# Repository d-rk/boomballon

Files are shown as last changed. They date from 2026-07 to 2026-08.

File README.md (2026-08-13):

<p align="center">
  Boom Balloon logo
</p>

# Boom Balloon

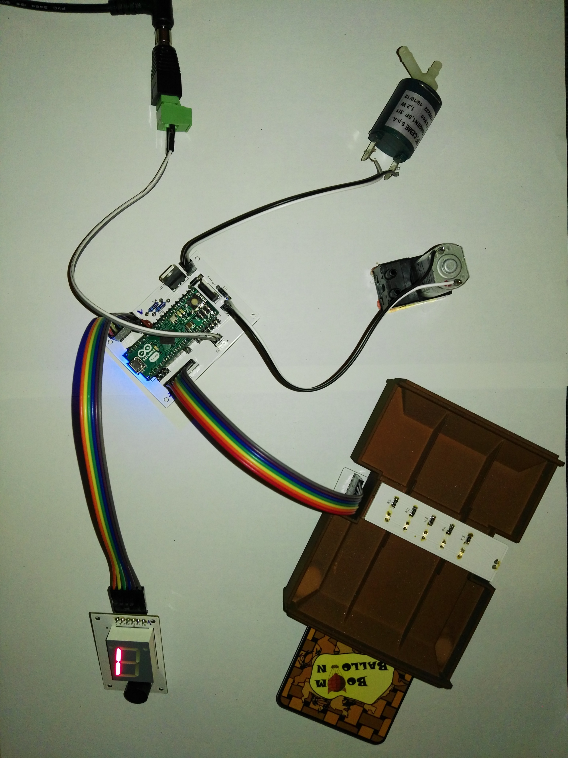
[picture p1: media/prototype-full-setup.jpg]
The Boom Balloon prototype — control board, 12 V pump, air valve, brick-styled card reader, and a lit 7-segment display, all wired together on the bench.


*The unit pictured is the earlier Arduino Micro prototype (the "prototype 2" generation); the current firmware targets the Arduino Nano (ATmega328P) — see [the story](docs/story.md#the-controller-from-micro-to-nano).*

**An electronic party game where players inflate a real balloon with punched cards until it bursts — whoever is holding the moment it pops loses.**

Players insert optically-coded punched cards into a reader; the firmware decodes each card and drives a 12 V pump (or a valve) to inflate or deflate a real balloon. A software model tracks the balloon's fill level as a simulated "volume" percentage. Cross 100 % on your turn and the balloon pops — you lose. The whole thing runs on an Arduino Nano (ATmega328P).

**Docs site:** https://boomballoon.github.io/

## In 30 seconds

- **Insert a coded card.** Each card is punched with a 5-bit optical pattern that the reader scans as it slides in.
- **The firmware acts.** It decodes the card and drives a 12 V pump to inflate the balloon — or opens a valve to let air back out.
- **The volume climbs.** A software model tracks the balloon's fill level as a percentage, ticking toward 100 % with every risky card.
- **Burst = you lose.** Cross 100 % on your turn and the balloon pops. Last player standing wins.

## Repo structure

- **`firmware/`** — Arduino/C++ firmware for the Arduino Nano (ATmega328P) control board.
- **`hardware/`** — PCB Fritzing files, PCB images, component datasheets, bill of materials, and enclosure CAD.
- **`cards/`** — card artwork and deck/code pointers.
- **`docs/`** — source for the MkDocs Material documentation site.
- **`media/`** — prototype photos.

## Build the docs locally

```bash
pip install -r docs/requirements.txt
mkdocs serve -f docs/mkdocs.yml
```

The site is built with [MkDocs Material](https://squidfunk.github.io/mkdocs-material/).

## Common tasks

A root `Makefile` wraps the everyday commands — run `make` to see them all:

| Command | What it does |
|---|---|
| `make build` | Build the firmware for the Arduino Nano |
| `make upload` | Build + flash the Nano (`PORT=…` to force the serial port) |
| `make mock` | Flash the no-hardware serial mock build (drive the game over serial) |
| `make monitor` | Open the serial console |
| `make docs` | Build the documentation site (`make docs-serve` to live-preview) |

Firmware targets need [PlatformIO](https://platformio.org/) (`pio`) on your
`PATH`; docs targets use a local virtualenv created by `make docs-setup`.

## Key pages

- [Build Guide — Overview & BOM](docs/build-guide/overview-bom.md)
- [The Card Deck](docs/gameplay/card-deck.md)

## Publishing

Docs are built and deployed to GitHub Pages automatically by [`.github/workflows/deploy-docs.yml`](.github/workflows/deploy-docs.yml) on every push to `main`, publishing at [https://boomballoon.github.io/](https://boomballoon.github.io/).

## License

© 2016–2026 Christian Volkmar and Dirk Wilden. Licensed under [CC BY-NC-SA 4.0](https://creativecommons.org/licenses/by-nc-sa/4.0/) — share and adapt for non-commercial use, with attribution, under the same terms. Commercial use requires permission (contact dirkwilden@gmail.com). See [LICENSE](LICENSE).

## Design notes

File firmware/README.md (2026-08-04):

# Boom Balloon Firmware

Firmware for the Boom Balloon device — **Arduino Nano (ATmega328P)**, C++11 on
the Arduino AVR core. The sources are a small OOP tree under `src/`
(`Main.cpp` provides `setup()`/`loop()`); see the
[Firmware Architecture](../docs/reference/firmware-architecture.md) doc for how
it fits together.

The build system is [PlatformIO](https://platformio.org/). It pins the
toolchain and Arduino core, so a clean checkout builds identically on Linux,
macOS, and Windows.

## Prerequisites

Install PlatformIO Core (CLI):

```bash
pip install platformio        # or: pipx install platformio
```

(Or use the PlatformIO IDE extension for VS Code — it drives the same
`platformio.ini`.) The first build downloads the `atmelavr` platform and the
AVR toolchain automatically.

## Build

```bash
cd firmware
pio run                       # builds all environments
pio run -e nanoatmega328      # just the Nano (the current board)
```

The compiled image lands at `.pio/build/<env>/firmware.hex`.

## Flash

Pick the environment that matches your board:

```bash
pio run -t upload -e nanoatmega328      # Arduino Nano, old bootloader (57600 baud)
pio run -t upload -e micro              # Arduino Micro (early-prototype board)
```

The project's Nanos are older clones with the old bootloader. If an upload
times out on a newer board, its bootloader expects 115200 baud — switch the
environment to `board = nanoatmega328new` in `platformio.ini`.

PlatformIO auto-detects the serial port; pass `--upload-port /dev/ttyUSB0`
(Linux CH340 clone), `/dev/ttyACM0` (genuine), or `COMx` (Windows) to force it.

## Serial monitor

```bash
pio device monitor            # 9600 baud, matching Serial.begin(9600)
```

Serial `printf` logging is always on. The format strings are kept in flash via
a `printf` → `printf_P(PSTR(...))` macro in `Constants.h`, so on the ATmega328P
logging costs almost no RAM (~16 bytes) and needs no build switch.

## Build switches (`src/Constants.h`)

The switches below are off by default. Enable one in `Constants.h`, or inject
it for a single build via the environment variable (note: `pio run -a "-D..."`
does **not** work — `-a` is an avrdude argument, not a compiler flag, so the
macro stays undefined):

- `AUTOSTART_GAME` — auto-starts a 2-player game on boot, for testing without
  the player-count detection flow.
- `MOCK_CODE_DETECTOR` / `MOCK_OUTPUT_DEVICE` — wire in the serial mocks from
  `src/Mock/` in place of the real devices, so the game can run with missing
  hardware. Each is independent, so you can mock one and keep the other real:
    - `MOCK_CODE_DETECTOR` — read card codes from the serial console (type a
      code + `<enter>`) instead of the photoresistor card reader.
    - `MOCK_OUTPUT_DEVICE` — print the balloon volume to serial (percentage +
      ASCII bar) instead of driving the pump/valve.

  Enable either or both. Pair them with `AUTOSTART_GAME` to boot straight into a
  game with no hardware at all:

  ```bash
  PLATFORMIO_BUILD_FLAGS="-D MOCK_CODE_DETECTOR -D MOCK_OUTPUT_DEVICE -D AUTOSTART_GAME" pio run -t upload -e nanoatmega328
  ```
- `DETECTOR_CALIBRATION` — replaces the game loop with a card-reader bring-up
  harness that prints raw photoresistor values (`<SPACE>` pauses output, `<TAB>`
  switches to changes-only output). Off by default (normal gameplay); build with
  `-D DETECTOR_CALIBRATION` to enable.

## Build verification

Both environments compile cleanly with no source changes:

```
nanoatmega328  SUCCESS
micro          SUCCESS
RAM:   [====      ]  36.3% (744 bytes / 2048)
Flash: [=====     ]  52.7% (16186 bytes / 30720)
```

CI (`.github/workflows/build-firmware.yml`) runs `pio run` on every push, so
the firmware is guaranteed to keep compiling.

## History

The early prototypes (2015–2018) ran on an **Arduino Micro** (ATmega32U4); the
build switched to the Nano in 2019. The pin assignments in `Main.cpp` predate
the switch and work on both boards, so the `micro` environment still targets
the original prototype hardware unchanged.

The firmware was originally built with **arduino-cmake** (a CMake toolchain)
driven by MinGW on Windows, with `avrdude` upload wrapped in `.bat` scripts.
That toolchain is from ~2013 and is incompatible with modern CMake (CMake 4
removed the pre-3.5 compatibility it relied on), so the project migrated to
PlatformIO. The old build files were removed; they remain in the git history
if you need them.

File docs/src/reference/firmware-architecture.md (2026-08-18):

# Firmware Architecture

This page describes how the firmware source is organised, how the program starts,
and how the pieces cooperate at run
time. For how to
compile and flash it, see [Firmware](../build-guide/firmware.md);
for the card encoding it depends on, see the
[Optical Code System](optical-codes.md).

The firmware is **plain object-oriented C++11**. It targets
the **Arduino Nano (ATmega328P)** — a small 8-bit AVR with 2 KB of RAM — which
shapes many of the design choices below (no STL, manual memory accounting, no
threads).

## Source layout

The source code for the firmware lives under `firmware/src/`:

| Area | Files | Role |
|---|---|---|
| Entry point | `Main.cpp` | Arduino `setup()` / `loop()`; wires everything together |
| Game logic | `Game.*`, `Player.*`, `PlayerChooser.*` | Turn flow, player ring, startup player-count selection |
| Cards | `Cards/Card.*` + subclasses | Card behaviours and the code→card factory |
| Devices | `Devices/CodeDetector.*`, `OutputDevice.*`, `PiezoBuzzer.*`, `SevenSegmentDisplay.*` | Hardware drivers |
| Mock devices | `Mock/CodeDetectorMock.*`, `Mock/OutputDeviceMock.*` | Serial stand-ins for the card reader and pump/valve, compiled in with `-D MOCK_CODE_DETECTOR` / `-D MOCK_OUTPUT_DEVICE` |
| Scheduling | `Tasks/Task.h`, `Tasks/TaskScheduler.*` | Cooperative multitasking |
| Helpers | `Helper/Vector.h`, `Helper/Diagnostic.h`, `Helper/Log.*` | STL-free container, RAM probe, `printf` logging |
| Config | `Constants.h` | Pins, codes, display glyphs, note frequencies, the flash-string `printf` macro, build switches (`AUTOSTART_GAME`, `MOCK_CODE_DETECTOR`, `MOCK_OUTPUT_DEVICE`, `DETECTOR_CALIBRATION`) |

The `Mock/` subtree lets the game run with **missing hardware**: build with
`-D MOCK_CODE_DETECTOR` and/or `-D MOCK_OUTPUT_DEVICE` and `Main.cpp` swaps that
device for a serial-driven stand-in (type codes in, watch the balloon volume
print out). Each is independent. See [Mock devices](#mock-devices) below for
how it works.

There is also a `Devices/` trio that is **not part of the running game**:
`Button`, `Led` and `SoundDetector` are now unused general-purpose drivers
 used during development. `SoundDetector` was used in experiment to detect the
 actual *pop* of the balloon and react to it, instead of the modelled
volume described in [How It Works](../how-it-works.md#the-balloon-volume-model).
It was discarded for the final game.

## Startup and object ownership

Most hardware drivers are **singletons**. Each exposes a public
`static X* instance` pointer, which `setup()` populates with a single `new` at
boot:

```cpp
// Main.cpp (excerpt)
SevenSegmentDisplay::instance = new SevenSegmentDisplay(PIN_9, PIN_10, PIN_8);
TaskScheduler::instance        = new TaskScheduler();
OutputDevice::instance         = new OutputDevice(PIN_6, PIN_7);
CodeDetector::instance         = new CodeDetector(PIN_A0, PIN_A1, PIN_A2, PIN_A3, PIN_A4);
PiezoBuzzer::instance          = new PiezoBuzzer(PIN_11);
PlayerChooser::instance        = new PlayerChooser(CODE_15, CODE_17, CODE_19, CODE_21, CODE_23);
```

Any part of the code can then reach a device through, for example,
`OutputDevice::instance->apply(...)` without passing pointers around. Because
these objects are created once and live for the whole program, there is no
teardown to worry about. The one non-singleton top-level object is the game
itself, declared as a **file-scope global** in `Main.cpp`:

```cpp
Game game;
```

`setup()` also seeds the random-number generator from the floating analog pin
`A5` (`randomSeed(analogRead(PIN_A5))`) — which is why the
[wiring](../build-guide/wiring.md) insists that `A5` stay unconnected.

The pin numbers, code values, and display glyphs all come from `Constants.h`,
which also carries four compile-time switches: `DETECTOR_CALIBRATION` and
`AUTOSTART_GAME`, described under [Build modes](#build-modes-and-logging), and
`MOCK_CODE_DETECTOR`/`MOCK_OUTPUT_DEVICE`, described under
[Mock devices](#mock-devices).

## Cooperative multitasking

The AVR has no operating system and the firmware uses no interrupt-driven
scheduler. Instead there is a tiny **cooperative** scheduler in
`Tasks/TaskScheduler`. The contract is a one-method interface:

```cpp
class Task {
    virtual bool applyChange(unsigned long timeMs) = 0;  // returns "still busy?"
};
```

A task advances its own animation by looking at the current time and returns
`true` while it still has work to do. Both `SevenSegmentDisplay` and
`PiezoBuzzer` are `Task`s, so a melody and a display animation are each just a
task that the scheduler ticks. The scheduler drives them on a fixed **20 ms**
cadence (`TaskScheduler::SLEEP_MS = 20`) and offers two ways to run:

- **`loop()` — blocking.** Ticks every registered task every 20 ms and keeps
  going until *all* of them report done, then clears the task list. Used when
  the game genuinely wants to wait for a jingle/animation to finish (e.g. the
  turn-change fanfare).
- **`iterate()` — non-blocking.** Ticks every task exactly once and returns
  immediately (clearing the list only once everything is done). Used when other
  work must continue in parallel.

The payoff shows up during **balloon inflation**. `OutputDevice::applyIntensities()`
runs a `delay(5 ms)` loop while it pulses the pump/valve, and inside that loop
it calls `TaskScheduler::instance->iterate()` on every step. So the buzzer tone
and the seven-segment "fill" animation keep advancing *concurrently* while the
balloon is being inflated or deflated, even though everything is single-threaded
and there are no interrupts.

## Game state and turn flow

### The player ring

Players are modelled as a **circular doubly-linked list** of `Player` objects
(`prevPlayer` / `nextPlayer`). The list is built by a *recursive* constructor:
`new Player(numPlayers)` creates the whole chain in one call and stitches the
ends together so that following `nextPlayer` forever cycles through the table.
Each `Player` owns its currently-attached cards in a `Vector<Card*>`.

Turn order is just "advance to `nextPlayer`". The
[Change of course](../gameplay/card-deck.md) cards work by literally swapping
every player's `prevPlayer`/`nextPlayer` pointers (`Player::changeDirection()`),
reversing the direction of play.

### Two-phase card insertion

`Game::loop()` reads the card reader once per iteration and drives a small state
machine around a single `currentCard` pointer:

1. **No card pending** (`currentCard == 0`): the detected code is handed to the
   `Card::playCard(code)` factory.
      - If it returns a card that **does not** need a target
        (`needsPlayerSelection() == false`), the card is applied to the *current*
        player immediately.
      - If it **does** need a target (the *Blocking*, *Devil's messenger*, and
        *Apocalypse* cards override `needsPlayerSelection()` to `true`), the card
        is held and the machine waits for a second card.
      - If the factory returns `nullptr`, the code is not a valid play card and
        the player gets an error beep.
2. **Card pending:** the next card must be a **player card**
   (`PlayerChooser::isPlayerCode`). If it is, the held card is attached to that
   target player; otherwise it is an error.

After a card is applied the machine sets `waitCardRemoved`, and the turn only
advances once the slot reads `CODE_ALL` (the "card removed" sentinel — see the
[optical codes](optical-codes.md#sentinel-codes) page). This is what forces the
"insert, then pull the card back out" rhythm of play described in the
[Rules](../gameplay/rules.md).

### Losing

There is exactly one loss condition, checked every `Game::loop()`:

```cpp
if (OutputDevice::instance->volume > 100.0f) { /* current player loses */ }
```

`volume` is the **modelled** balloon fill (a software time-integral, not a
sensor reading — see [How It Works](../how-it-works.md#the-balloon-volume-model)).
When it exceeds 100 %, the current player loses, the device runs a reset/deflate
sequence, and the game waits for a card to be removed before it can be
restarted.

## The card model

`Card` is an abstract base class. Concrete behaviours subclass it and override
`play()`:

- **`VolumeCard`** is the workhorse: apply a percentage volume change at a given
  intensity, then discard itself. Most "pressure" cards are just `VolumeCard`
  with different numbers.
- Subclasses add behaviour: `ChangeDirectionCard` (volume change **and** reverse
  the player ring), `AngelCard` / `DevilCard` (delayed relief / malicious
  inflate), `FiftyFiftyCard` (random ±50 %), `UpDownCard` (oscillate),
  `MissRoundCard`, `SuddenDeathCard`, and `PushToLimitCard` (inflate to 99 %).

The mapping from optical code to card lives in a single static factory,
`Card::playCard(code)`, which is a plain `switch` — the authoritative,
code-verified rendering of that mapping is the deck catalog in
[The Card Deck](../gameplay/card-deck.md). A card marks itself `discard = true`
when its effect is spent, and `Player::loop()` sweeps discarded cards out of the
player's vector.

## Helpers and diagnostics

Because the AVR toolchain here ships no STL, the firmware carries a few
hand-rolled utilities:

- **`Vector<T>` (`Helper/Vector.h`)** — a minimal `std::vector`-like dynamic
  array (`push_back`, iterators, copy-assign, grow-by-5 reserve). Used for the
  per-player card list and the scheduler's task list.
- **`freeRam()` (`Helper/Diagnostic.h`)** — reports free SRAM by measuring the
  gap between the heap break and the stack. Handy on a 2 KB part; it is printed
  on each turn change.
- **`Log` (`Helper/Log.cpp`)** — redirects C `printf` to the Arduino `Serial`
  port, so the rest of the code can log with ordinary `printf(...)` format
  strings. Logging is always on; a `printf` → `printf_P(PSTR(...))` macro in
  `Constants.h` keeps the format strings in flash so it costs almost no RAM.

## Build modes and logging

`Constants.h` exposes several compile-time knobs that change what gets built:

- **`DETECTOR_CALIBRATION`** replaces the game `loop()` with a bring-up harness
  that just prints raw analog readings from the card reader, used to tune the
  reader thresholds. Off by default (the normal game). See the
  [Optical Code System](optical-codes.md#calibration-harness).

Serial `printf` logging is always compiled in — the format strings live in
flash (`printf_P`/`PSTR`), so it costs almost no RAM.

There is also an `AUTOSTART_GAME` switch that skips the player-count selection
and jumps straight into a 2-player game — a convenience for testing.

## Mock devices

The `Mock/` subtree is a **desk-testing path**: run the game with missing
hardware. Each device is mocked independently by its own build flag, so you can
stand in for one and keep the other real, or mock both:

- **`CodeDetectorMock`** (build with `-D MOCK_CODE_DETECTOR`) replaces
  `CodeDetector`. Instead of reading the five photoresistors, it reads a card
  code you type into the serial console — a number followed by `<enter>`
  "inserts" that card, an empty line "pulls it out" again. It subclasses
  `CodeDetector` and overrides `readCode()`.
- **`OutputDeviceMock`** (build with `-D MOCK_OUTPUT_DEVICE`) replaces
  `OutputDevice`. Instead of driving the 12 V pump and valve, it prints the
  balloon volume to serial after each inflate or deflate, as a percentage and a
  little ASCII bar. It keeps the real volume model (fill/deflate timing) and
  only swaps out the physical pin writes.

Either flag can be set on the command line or uncommented in `Constants.h`.

To make the output mock possible without duplicating the volume model,
`OutputDevice` exposes three protected virtual hooks — `writeMotor()`,
`writeValve()`, and `afterApply()` — that the real device implements as pin
writes and a no-op, and the mock overrides to suppress hardware and report
volume.

Because the mocks talk over serial, a build with either mock also gets a 2.5 s
startup delay so the serial link settles before the opening prompt prints
(`printf` logging is always on). Combine them with `-D AUTOSTART_GAME` to boot
straight into a 2-player game and watch the balloon fill on the console.

## The unbuilt mode system

There was a design for a **game-mode selector** built around the **Yin Yang**
card (optical code **27**) that was specced but never implemented. The idea,
captured in the design note *Anforderungen Moduswechsel* ("mode-change
requirements"), was that the Yin Yang card would cycle through four play modes:
you insert the card repeatedly *before* committing a player card, each insertion
advances the selected mode (shown on the display), and you pull the card out once
the mode you want is selected.

The four intended modes were:

| Mode (German) | English gloss | Display glyph | Behaviour |
|---|---|---|---|
| Standard | Standard | `S` | Normal game, no extras. |
| Himmel | "Heaven" | circle | Every third round, deflate a **random** player's balloon a little. |
| Hölle | "Hell" | minus | Every third round, inflate a **random** player's balloon a little. |
| Provokation | "Provocation" | `P` | Start the game with the balloon already partly filled. |

!!! note "What actually shipped for code 27"
    The mode system was never built. In the shipped firmware, optical code **27**
    is instead wired to a single card behaviour — **`PushToLimitCard(255)`**,
    which inflates the balloon to **99 %** in one go (see
    [The Card Deck](../gameplay/card-deck.md)). So the Yin Yang card exists and is
    playable, but as a one-shot "push to the limit" wildcard rather than as the
    four-way mode selector its design note envisioned.

The design note itself is explicit that these were early ideas ("*these are just
ideas for now*"), so nothing here was a broken promise — it is simply a feature
that stopped at the design stage.

**Source:** the original German design note is archived alongside this page as
[`anforderungen-moduswechsel.txt`](anforderungen-moduswechsel.txt).

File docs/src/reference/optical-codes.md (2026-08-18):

# Optical Code System

Every card carries a 5-bit optical code encoded in a set of holes.
The electronics turn the holes into an analog signal which the firmware then reads.

For what each code *means* (which card, which effect), see the deck
catalog in [The Card Deck](../gameplay/card-deck.md); for the code that
implements the reader, see [Firmware Architecture](firmware-architecture.md).

## How the reader works

The card reader is two facing PCBs with a slot between them (see the
[card-reader module](../build-guide/modules/card-reader.md)):

- The **Lichtmodul** ("light module") carries **5 LEDs** that shine across the
  slot.
- The **Fotomodul** ("photo module") carries **5 photoresistors** directly
  opposite them.

A card is an opaque rectangle punched with up to five holes, one per
LED/photoresistor pair. Where the card has a **hole**, light passes through and
the photoresistor sees it; where the card is **solid**, the light is blocked. So
each of the five positions reads as one **bit** — light (1) or dark (0) — and the
five bits together form an integer from **0 to 31**.

The five photoresistors are wired to the Arduino's analog inputs **A0–A4** (see
the [wiring](../build-guide/wiring.md)). The firmware
(`Devices/CodeDetector`) reads all five with `analogRead()`, thresholds each into
a bit, and assembles the result into a single value.

## Bit positions

The five analog pins together form a binary representation of an integer:
pin `A`*i* is bit *i* of the code, so its value is `2^i`. The order comes
straight from the firmware's pin array (`Main.cpp`: `CodeDetector(PIN_A0,
PIN_A1, PIN_A2, PIN_A3, PIN_A4)`), where `A0` fills bit 0 and `A4` fills bit 4:

| Pin | A0 | A1 | A2 | A3 | A4 |
|---|---|---|---|---|---|
| Bit | 0 | 1 | 2 | 3 | 4 |
| Value (2^bit) | 1 | 2 | 4 | 8 | 16 |

A code is the binary number formed by reading each **open (holed)** position
as a `1` and each solid position as a `0`.

!!! example "example — the Player 1 card"
    The `1 Spieler` (Player 1) card has the pattern `01111` (bit 4 down to bit 0):

    | A4 (bit 4) | A3 (bit 3) | A2 (bit 2) | A1 (bit 1) | A0 (bit 0) |
    |---|---|---|---|---|
    | 0 | 1 | 1 | 1 | 1 |

    Binary `01111` = 8 + 4 + 2 + 1 = **15**.

## Mirror invariance

A card is a physical rectangle, and nothing stops a player from pushing it in
**rotated 180°**. When that happens the reader sees the hole pattern
**bit-reversed**. the code read from the flipped card is the mirror image of the
code read from the upright card.

The firmware makes reading **orientation-independent** by canonicalising every
code: it computes the bit-reversal of the detected value and always stores the
**smaller of the two**. So a card and its 180° rotation both resolve to the same
canonical code, and the deck is designed so that no two *different* cards collide
under this rule.

The codes that are **not** palindromic pair up as follows. Bits are written
`A4 A3 A2 A1 A0`, so the mirror's bit string is just the canonical's read
backwards:

| Canonical code | Canonical bits | Mirror bits | Mirror code |
|---|---|---|---|
| 1 | `00001` | `10000` | 16 |
| 2 | `00010` | `01000` | 8 |
| 3 | `00011` | `11000` | 24 |
| 5 | `00101` | `10100` | 20 |
| 6 | `00110` | `01100` | 12 |
| 7 | `00111` | `11100` | 28 |
| 9 | `01001` | `10010` | 18 |
| 11 | `01011` | `11010` | 26 |
| 13 | `01101` | `10110` | 22 |
| 15 | `01111` | `11110` | 30 |
| 19 | `10011` | `11001` | 25 |
| 23 | `10111` | `11101` | 29 |

Codes that read the same upside-down (the palindromes `0`, `4`, `10`, `14`,
`17`, `21`, `27`, `31`, …) are their own mirror and need no pairing — they are
read identically whichever way round the card goes in.

## Thresholding, calibration, and debounce

Photoresistors are analog and noisy, and the raw `analogRead()` value for
"bright" differs from channel to channel because of component tolerances and
wiring. `CodeDetector` handles this in three steps.

**1. Per-pin calibration.** Each channel's raw 0–1023 reading is rescaled to a
normalised 0–100 range with Arduino's `map()`, using a *different* upper
calibration point per pin (the lower point is shared):

```cpp
case 0: value = map(value, 20, 950, 0, 100); break;  // A0
case 1: value = map(value, 20, 910, 0, 100); break;  // A1
case 2: value = map(value, 20, 885, 0, 100); break;  // A2
case 3: value = map(value, 20, 900, 0, 100); break;  // A3
case 4: value = map(value, 20, 895, 0, 100); break;  // A4
```

These per-pin numbers were found empirically with the calibration harness
below; if the reader hardware changes, they are what you re-tune.

**2. A threshold band with hysteresis.** Rather than a single cutoff, the
normalised value is compared against two thresholds — a `MIN_THRESHOLD` and a
`MAX_THRESHOLD` (20 and 28 in the normalised 0–100 space). A bit is only cleared
to 0 when its value drops **below** the low threshold, and only set to 1 when it
rises **above** the high threshold; in the gap between them the bit keeps its
previous state. This dead-band stops a marginal channel from flickering between
0 and 1 as a card slides through.

**3. Time debounce.** A newly-read code must remain stable for at least
**`TIME_WAIT_MS` (200 ms)** before it is accepted as the new *active* code
(`codeChanged()` remembers when the reading last changed and waits out the
window). This absorbs the transient partial patterns produced while a card is
physically being pushed in or pulled out by hand.

### Calibration harness

Building the firmware with `-D DETECTOR_CALIBRATION` replaces the game loop with a bring-up tool. Instead of playing, it continuously prints each channel's raw
normalised value alongside the decoded bits and the resulting code. Each line has
three columns: the five normalised values for `A0`–`A4`, the thresholded bits in
the same `A0`-first order, and finally `activeCode = mirror` (the canonical code
and its 180° mirror). For example, inserting the **Player 1 card** (code **15**,
holes `01111` from the example above) reads as:

```
 98  95  97  92   8  |  1 1 1 1 0   |  15 = 30
```

Reading the bits `A0`-first gives `1·1 + 1·2 + 1·4 + 1·8 + 0·16 = 15`; the low
`A4` value (8, below the threshold) is the single dark position, and 15's mirror
is 30, so the reader reports `15 = 30`.

Over the serial monitor, `<SPACE>` pauses the stream and `<TAB>` toggles
"changes only" output. This is the mode you use to pick the per-pin `map()`
constants and to verify a freshly assembled reader before trusting it in a game.

## Sentinel codes

Two of the 32 possible values are reserved as **sentinels** rather than cards:

| Code | Name | Meaning |
|---|---|---|
| `0` | `CODE_NONE` | All positions dark — no card, or a card not yet fully inserted. |
| `31` | `CODE_ALL` | All five positions lit — an **empty slot** / "card removed" signal. |

`CODE_ALL` is central to game flow: after a card is played, the machine waits for
the slot to read `31` (the card pulled back out) before advancing the turn, and a
`31` after the game ends is what triggers a restart. See
[Two-phase card insertion](firmware-architecture.md#two-phase-card-insertion) for
how the game consumes these. Because a real card can never present all five holes
*and* be a play card, `0` and `31` are safe to treat as "nothing is being
played."

Everything else — the codes that actually map to cards and their effects — is
catalogued in [The Card Deck](../gameplay/card-deck.md).

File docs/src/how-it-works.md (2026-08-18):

# How It Works

Boom Balloon looks like a toy and behaves like a small embedded system. There is a real balloon, a real pump, and a real valve — but the thing everyone is nervous about, the balloon's fill level, is tracked entirely in software. This page explains the model behind the game, how the machine reads its cards, and what actually happens during a single turn.

## The balloon-volume model

The number that decides who loses is a **software model of the balloon's volume**, expressed as a percentage. The firmware does not measure air pressure and it does not sense the balloon at all. Instead, it keeps a running total based on time:

- When the **pump** runs, the modelled volume rises in proportion to how long it runs.
- When the **valve** opens, air escapes and the modelled volume falls, again over time.

In other words, the volume is a **time-integral of pump and valve activity** — the machine knows how much it has inflated and deflated because it is the one doing the inflating and deflating. When the modelled volume passes **100 %**, the balloon is considered burst and the current player loses.

!!! note "No pressure sensor"
    Because the volume is modelled rather than measured, there is no feedback loop from the physical balloon. The codebase does contain a `SoundDetector` class — the seed of a pop-detection idea — but it is **not used** by the game.

This is a deliberate design: it keeps the hardware cheap and reliable, and it means the machine can also raise or lower the *simulated* volume for cards whose effect is about strategy rather than a literal puff of air.

## The cards are the input

Boom Balloon has no buttons for gameplay. The only way a player interacts with the machine is by inserting a **card (Spielkarte, "playing card")** into the reader. Each card carries a **5-bit optical code** — a pattern of punched holes — that the reader scans as the card slides in.

A small, well-defined code space (5 bits) keeps the reader simple and the deck easy to print, while still giving enough distinct values to cover every card type in the game. The firmware handles the messy realities of a physical card being pushed in by hand: it **debounces** the optical signals so a shaky insertion is not misread, and it correctly interprets a card inserted the "wrong" way by handling the **180°-rotation mirror** of the code.

For the full specification — the bit layout, how the codes map to card effects, and the mirror-handling rules, see the [Optical Code System](reference/optical-codes.md) reference.

## A single turn, step by step

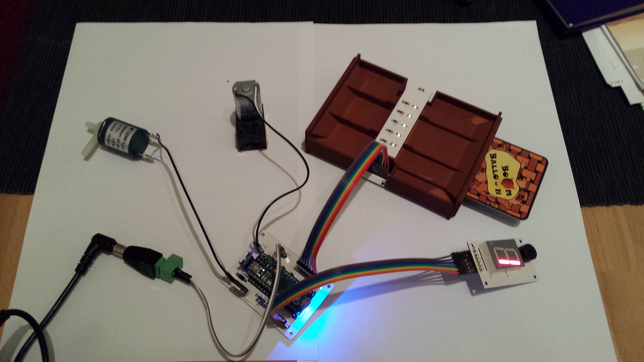
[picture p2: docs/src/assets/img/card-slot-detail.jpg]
The brick-styled card reader tray with a printed Boom Balloon card resting alongside, ready to be scanned.


Here is what happens from the moment it is your turn:

1. **Insert your card.** You slide a card into the reader. The optical sensors pick up the hole pattern as the card passes.
2. **The firmware decodes it.** After debouncing the signals and correcting for insertion direction, the 5-bit code is resolved to a specific card.
3. **Pick a target, if the card asks.** Some cards act on a chosen opponent rather than yourself. In that case the card's effect is directed at another player (selected via a player card, *Spielerkarte*), so you can push someone else toward the burst.
4. **The effect plays out.** The decoded card is turned into a `Card` object that applies its effect — running the pump to inflate, opening the valve to deflate, accompanied by a **buzzer** sound and an **animation on the 7-segment display**.
5. **Pull the card out.** Removing the card clears the reader and ends the action.
6. **Next player.** Play passes on. The modelled volume carries over, a little higher or lower than before. everyone tries not to burst the balloon.

---

Want more detail? The [card deck](gameplay/card-deck.md) covers what each card does, the [build guide](build-guide/overview-bom.md) covers the hardware, and the [firmware architecture](reference/firmware-architecture.md) reference explains how the code is put together.

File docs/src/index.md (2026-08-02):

# Boom Balloon

<p align="center">
  Boom Balloon logo
</p>

The Boom Balloon prototype — control board, 12 V pump, air valve, brick-styled card reader, and a lit 7-segment display, all wired together on the bench.

*The unit pictured is the earlier [Arduino Micro prototype](story.md#the-controller-from-micro-to-nano) (the "prototype 2" generation); the current firmware targets the Arduino Nano (ATmega328P).*

**An electronic party game where players inflate a real balloon with punched cards until it bursts — whoever is holding the moment it pops loses.**

Boom Balloon turns a game of nerve into hardware you can feel. Every card you play sends a puff of air into a genuine rubber balloon. It swells, the tension rises, and nobody knows which card will be the one too many. It is a *Buckaroo!*-style dare for the electronics age: a microcontroller, a pump, a valve, and a deck of optically-coded cards that the machine reads all by itself.

## In 30 seconds

- **Insert a coded card.** Each card is punched with a 5-bit optical pattern that the reader scans as it slides in.
- **The firmware acts.** It decodes the card and drives a 12 V pump to inflate the balloon — or opens a valve to let air back out.
- **The volume climbs.** A software model tracks the balloon's fill level as a percentage, ticking toward 100 % with every risky card.
- **Burst = you lose.** Cross 100 % on your turn and the balloon pops. Last player standing wins.

[How It Works](how-it-works.md){ .md-button .md-button--primary }
[The Card Deck](gameplay/card-deck.md){ .md-button }
[Build Guide](build-guide/overview-bom.md){ .md-button }

## A look inside

<div class="grid" markdown>

The brick-styled card reader with a printed Boom Balloon card resting by the open tray.

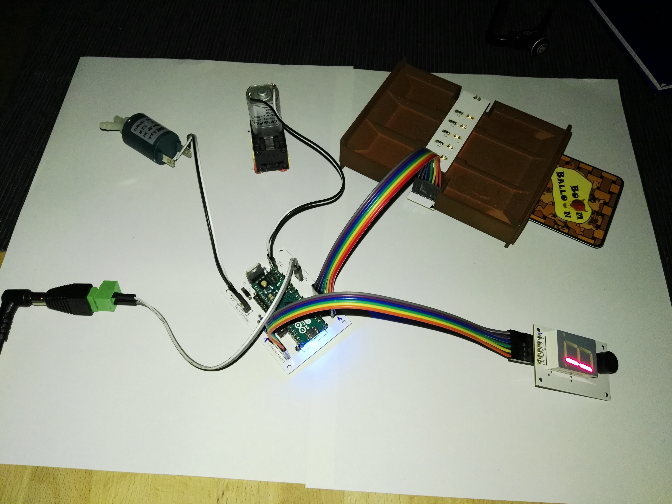
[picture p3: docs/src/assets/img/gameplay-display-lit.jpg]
The 7-segment display lit up, showing the active player during a turn.


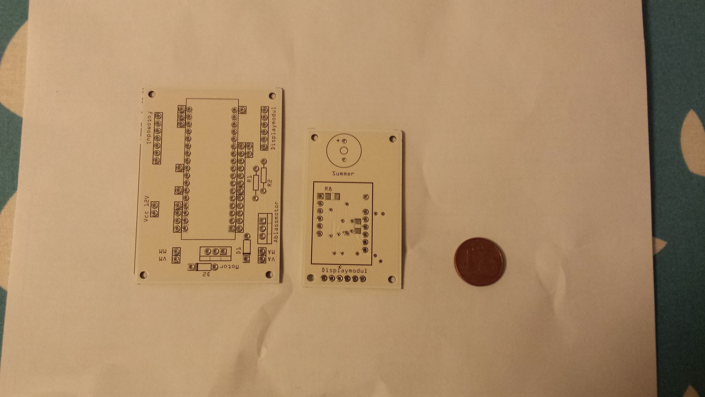
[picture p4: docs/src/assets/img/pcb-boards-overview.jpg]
The bare, fabricated custom PCBs before any components were soldered on.


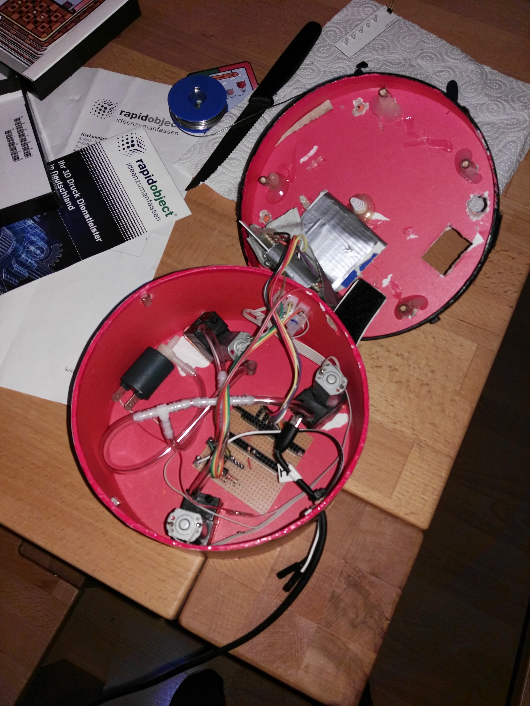
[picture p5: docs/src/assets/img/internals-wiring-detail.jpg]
The wiring detail: pump, valve, and reader all routed back to the Arduino-based control board.


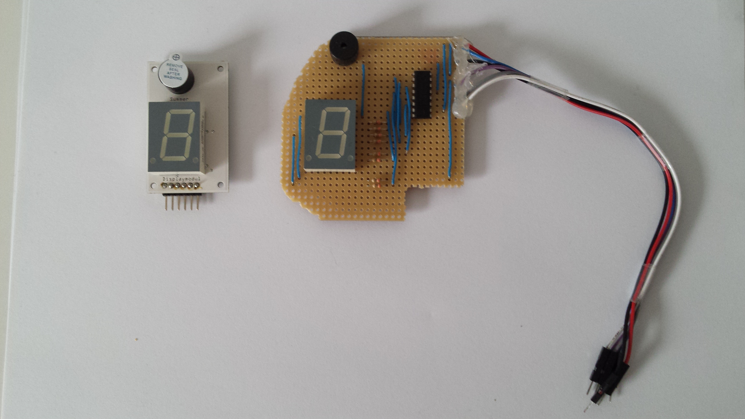
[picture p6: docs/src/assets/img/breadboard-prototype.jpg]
Early hand-soldered display and buzzer electronics on perfboard, beside a purchased 7-segment display module.


</div>

---

Boom Balloon was a hobby and pre-commercial project built between roughly 2016 and 2018. It reached a working, multi-unit prototype with complete firmware before enclosure costs stalled it. [Read the full story](story.md).

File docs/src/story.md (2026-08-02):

# The Story

Boom Balloon began the way a lot of good ideas do: two friends, a silly premise, and the stubbornness to actually build it. Between roughly **2016 and 2018**, Dirk and Christian turned "what if a machine inflated a real balloon until it burst?" into a working electronic party game — designed, coded, printed, and prototyped in multiple units. It was a hobby project with a serious, pre-commercial ambition behind it: the goal was a boxed product you could put on a shelf.

## From breadboard to game

Early hand-built electronics: a hand-soldered perfboard carrying a buzzer, a DIP IC, and a 7-segment display (right), beside a purchased display-and-buzzer module (left).

The concept is deceptively simple — a balloon, a pump, and the nerve to keep playing — but making it read cards on its own was where the engineering lived. Instead of buttons, Boom Balloon uses a deck of cards punched with an optical code, and a custom reader that scans each card as it slides in. That decision shaped everything that followed: the card artwork, the reader mechanism, the firmware, and eventually the enclosure all had to serve the card.

## Timeline

**2016 — First prototypes and the card reader.**
The earliest builds proved the core loop on a breadboard: a card goes in, the machine inflates or deflates, a display tracks the game. In parallel came the first CAD work for the optical card reader — the brick-styled tray that gives the game its look and does the actual scanning.

**2017 — Art, bill of materials, and a real deck.**
With the mechanics working, the project turned to polish. The card artwork was finalized, the bill of materials was locked down, and a full deck of cards was printed and boxed. This was the year Boom Balloon started to look and feel like a product rather than a bench experiment.

**2018 — Toward an enclosure.**
The final push was housing the electronics. Enclosure options were quoted and a sticker was produced for a metal-box version of the game. This is also where the project met its practical ceiling: a nice enclosure at hobby quantities is expensive, and the numbers did not add up for a small run.

## The controller: from Micro to Nano

Under the hood, Boom Balloon runs on an **Arduino** microcontroller. The design was migrated from an earlier board built around the **Arduino Micro** — the "prototype 2" generation — to the **Arduino Nano** (ATmega328P) used in the current prototype. The move brought the electronics onto the compact, low-cost controller that the finished firmware targets today.

The fabricated custom PCBs before assembly — the larger control board (Steuermodul), its connector silkscreens reading Fotomodul (photo reader), Displaymodul (display), and Ablassmotor (deflate motor), beside the smaller display module, next to a coin for scale.

## Where it landed

Boom Balloon is a **functional, multi-unit prototype**. The firmware is complete — cards are decoded, the balloon-volume model runs, and the game plays end to end with sound and a live display. What never happened was the leap to a retail product: the **housing was cost-blocked**, and the **retail boxes were never ordered**.

Across all the prototype work — boards, pump, valve, reader, printed cards, and enclosure quotes — the total spend came to roughly **€577**. For a project that produced a genuinely playable machine and a printed deck, that is a modest price for the lesson every hardware hobbyist eventually learns: the electronics are the easy part; it is the box around them that decides whether a prototype becomes a product.

This site is the archive of that work — a place to see how Boom Balloon plays, how it was built, and how the machine reads its cards. Start with [How It Works](how-it-works.md), or browse [the card deck](gameplay/card-deck.md) and the [build guide](build-guide/overview-bom.md).

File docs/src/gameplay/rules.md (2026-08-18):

# Rules

Boom Balloon is a party game of nerve and sabotage. A real balloon is slowly filled by the machine as players take turns. Every action happens by inserting a **card** into the reader.

**Your goal is simple:** don't be the player who makes the balloon burst.

## What you need

- The Boom Balloon machine, powered on, with a balloon fitted.
- The card deck (see [The Card Deck](card-deck.md) for the full catalog).
- **At least two players.** A `1 Spieler` ("1 player") card exists, but only as a target card — it cannot start a game.

## Setting up a game

1. **Shuffle the deck** and **deal each player 4 cards**, face down — this is their hand. The rest of the deck stays face down as a hidden **draw pile**.
2. **Power on.** The 7-segment display shows a dot `.` when it is ready.
3. **Choose the number of players.** Insert one of the **`2 Spieler`…`5 Spieler`** ("2–5 players") cards. This selects the game size — for example, insert `4 Spieler` for a four-player game.
4. **Start.** Pull the card back out. Removing it begins the game, and a random **jingle** plays — either the *Beverly Hills Cop* theme or the *A-Team* theme.
5. **Lay out the player cards.** Place the `1 Spieler`…`5 Spieler` card in front of each player, one per player, in **clockwise seating order**. These stay on the table for the rest of the game, so everyone always knows whose player number is whose.

!!! tip "The player cards do double duty"
    The `2 Spieler`…`5 Spieler` cards choose the game size at startup, and during play the `1 Spieler`…`5 Spieler` cards laid out in front of each player are also used to **pick a target** for cards that act on an opponent — grab that player's card off the table and insert it.

## Taking a turn

On each turn the display shows a **`P`** followed by the current **player number**, so everyone knows whose turn it is.

1. **Choose a card from your hand.** The current player picks one of their 4 cards and slides it into the reader.
2. **Resolve the effect:**
    - **Immediate-effect cards** apply at once — the pump inflates or the valve deflates, with a buzzer sound and a display animation.
    - **Target cards** — **Teufelsbote** (Devil's messenger), **Blockierung** (blocking / miss a round), and **Weltuntergang** (apocalypse) — do not act on you. After playing one, the machine waits for a second card: grab the target player's **player card** off the table and insert it to choose which player the effect hits.
3. **Pull the card out to advance.** Removing the played card clears the action and passes play to the **next player**.
4. **Draw back up to 4.** Before the next player goes, whoever just played draws a new card from the deck, bringing their hand back to 4.

The balloon volume carries over from turn to turn, creeping up or down with each card, until someone makes
the balloon burst.

## Direction of play

Play normally passes from one player to the next in a fixed order. The **Kurswechsel** ("change of course") cards **reverse the direction of play** — so a well-timed reversal can send a nasty situation right back toward the player who set it up.

## Winning and losing

Whoever's turn it is when the balloon bursts **loses** the round.

After a loss the device **auto-deflates** the balloon. To play again, remove the card from the machine and it **restarts** for a fresh game.

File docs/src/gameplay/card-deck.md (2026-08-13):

# The Card Deck

This page is the **authoritative catalog** of the Boom Balloon deck. Every card's German name, English gloss, optical code, effect, and deck count is listed here; printed face values are shown in the card captions above.

## The cards

The full deck, card by card. Printed face values are shown in the captions; see [the catalog](#the-catalog) below for each card's optical code and effect.

### Effect cards

<div class="card-grid" markdown>
<figure markdown="span">
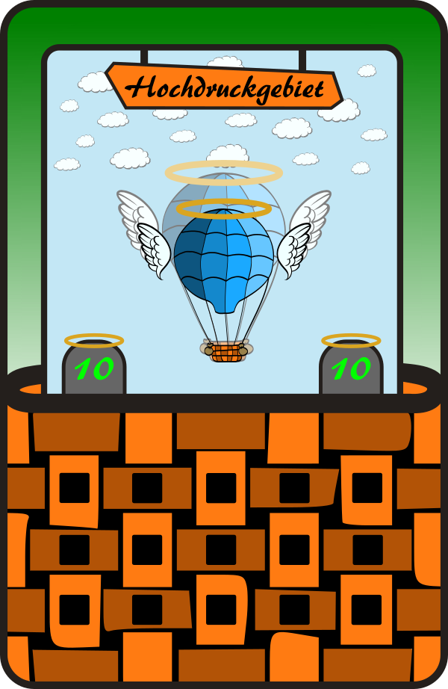
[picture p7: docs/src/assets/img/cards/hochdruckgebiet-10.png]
Hochdruckgebiet 10

<figcaption>Hochdruckgebiet 10</figcaption>
</figure>
<figure markdown="span">
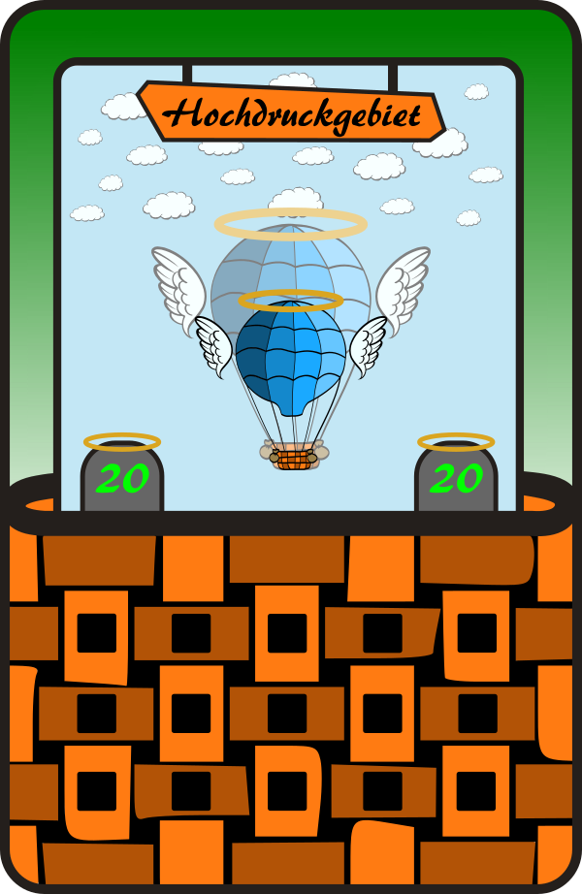
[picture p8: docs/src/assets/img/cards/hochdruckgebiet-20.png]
Hochdruckgebiet 20

<figcaption>Hochdruckgebiet 20</figcaption>
</figure>
<figure markdown="span">
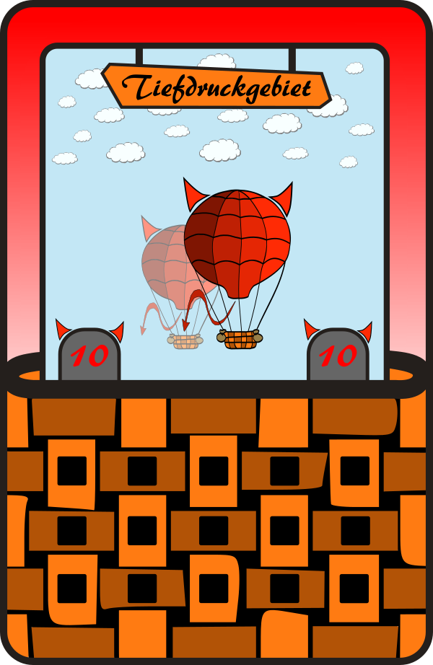
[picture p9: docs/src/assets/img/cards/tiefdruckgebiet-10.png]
Tiefdruckgebiet 10

<figcaption>Tiefdruckgebiet 10</figcaption>
</figure>
<figure markdown="span">
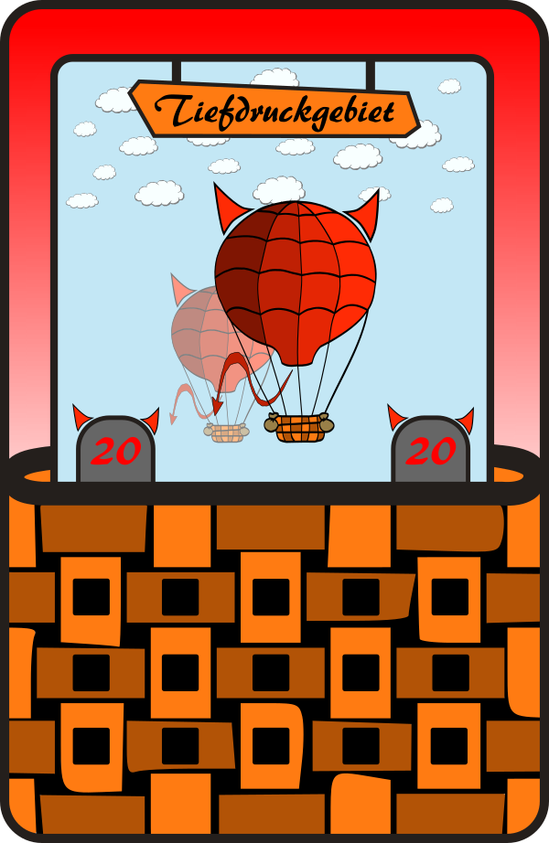
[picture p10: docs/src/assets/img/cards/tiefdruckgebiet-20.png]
Tiefdruckgebiet 20

<figcaption>Tiefdruckgebiet 20</figcaption>
</figure>
<figure markdown="span">
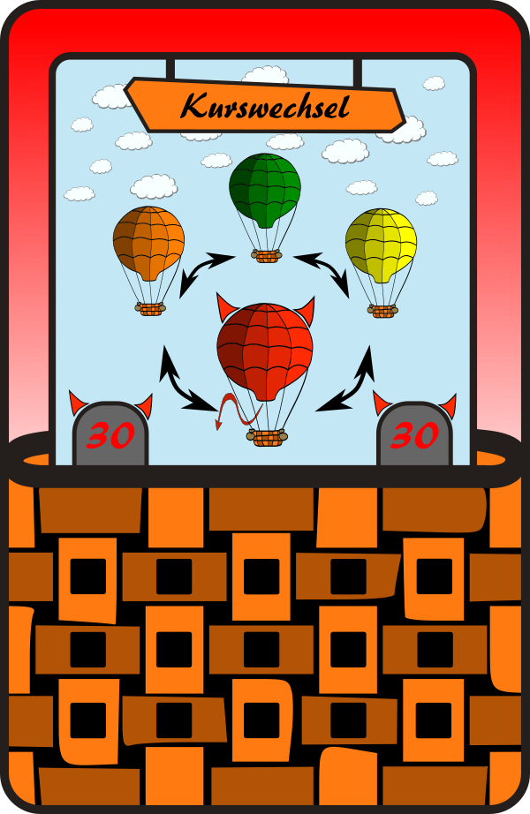
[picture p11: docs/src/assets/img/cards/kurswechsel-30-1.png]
Kurswechsel 30, deflate and reverse

<figcaption>Kurswechsel 30 ↓</figcaption>
</figure>
<figure markdown="span">
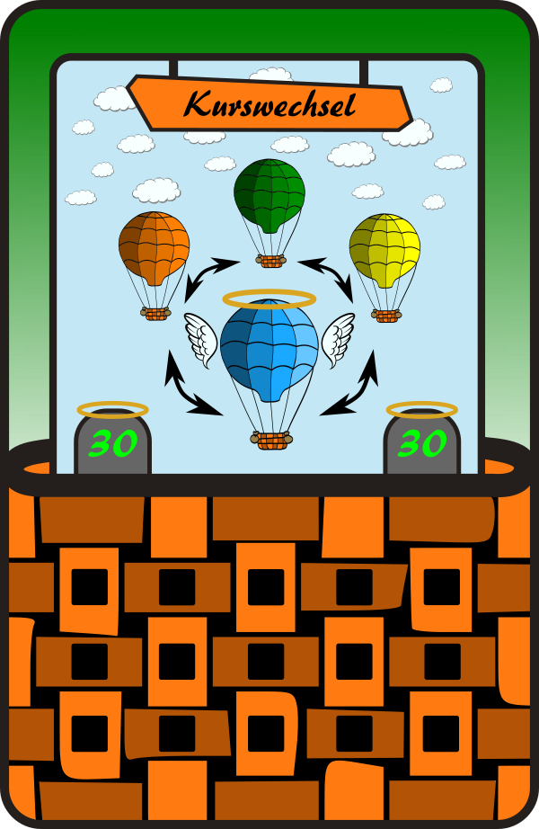
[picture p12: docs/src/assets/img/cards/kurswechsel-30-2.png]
Kurswechsel 30, inflate and reverse

<figcaption>Kurswechsel 30 ↑</figcaption>
</figure>
<figure markdown="span">
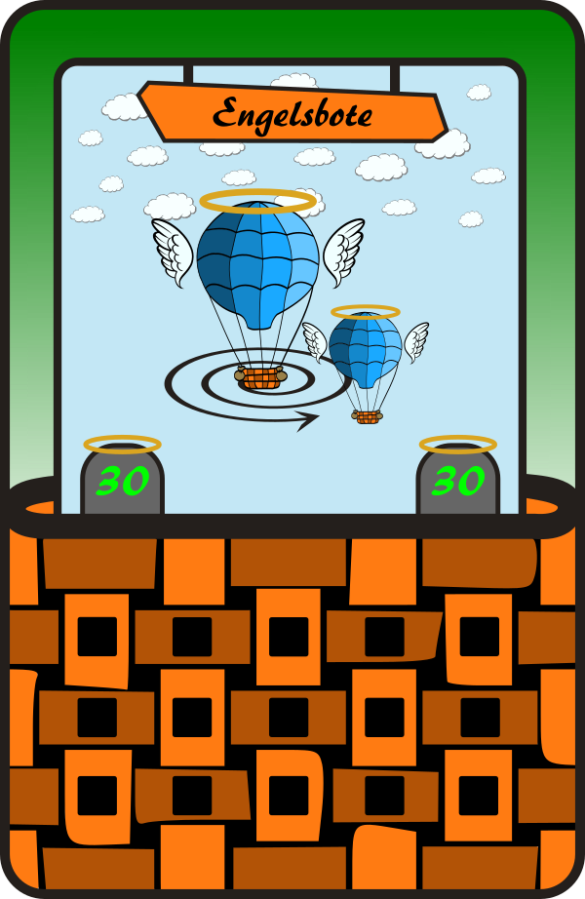
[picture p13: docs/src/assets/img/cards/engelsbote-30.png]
Engelsbote 30

<figcaption>Engelsbote 30</figcaption>
</figure>
<figure markdown="span">
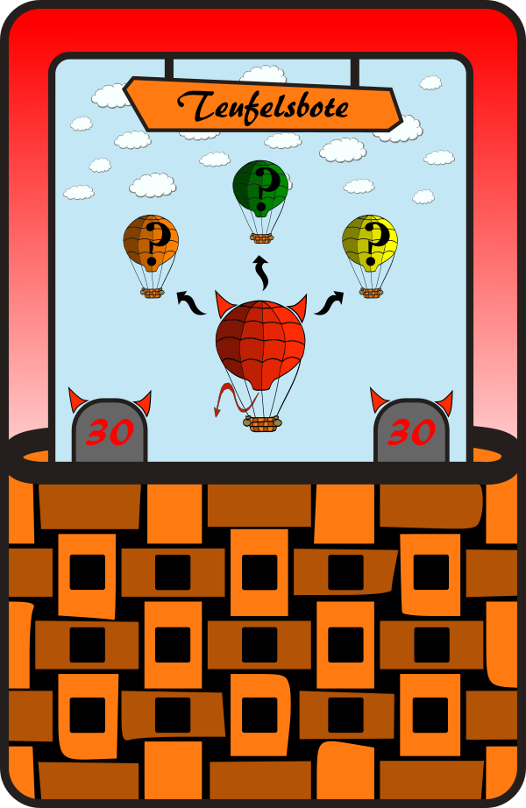
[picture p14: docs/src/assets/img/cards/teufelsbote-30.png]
Teufelsbote 30

<figcaption>Teufelsbote 30</figcaption>
</figure>
<figure markdown="span">
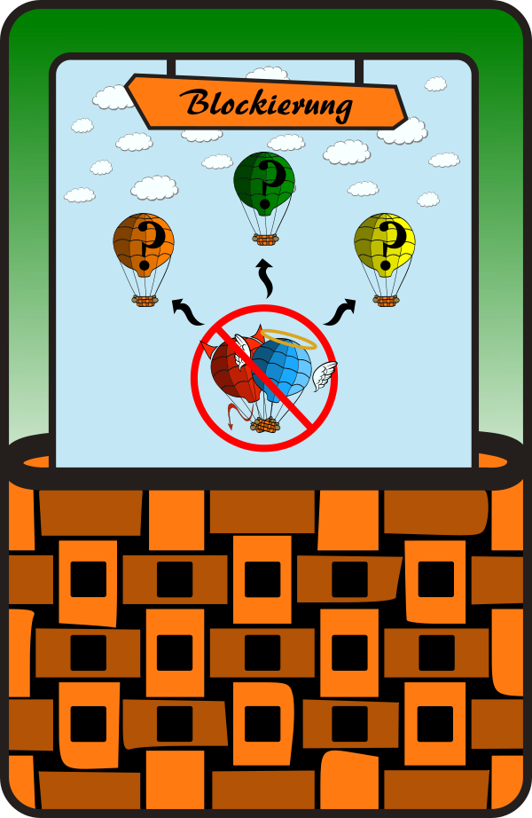
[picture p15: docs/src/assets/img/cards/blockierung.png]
Blockierung

<figcaption>Blockierung</figcaption>
</figure>
<figure markdown="span">
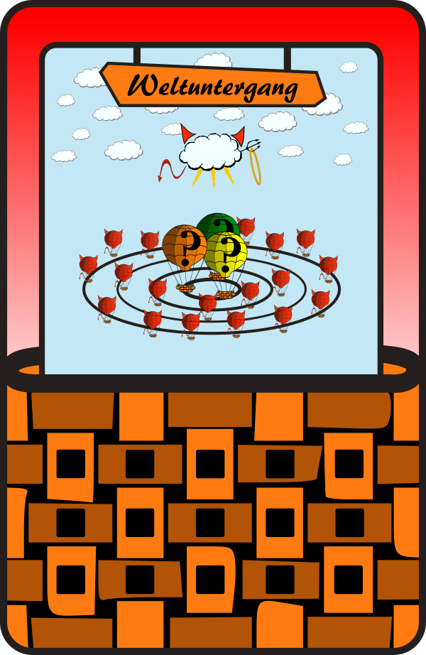
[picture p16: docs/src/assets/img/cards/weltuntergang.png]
Weltuntergang

<figcaption>Weltuntergang</figcaption>
</figure>
<figure markdown="span">
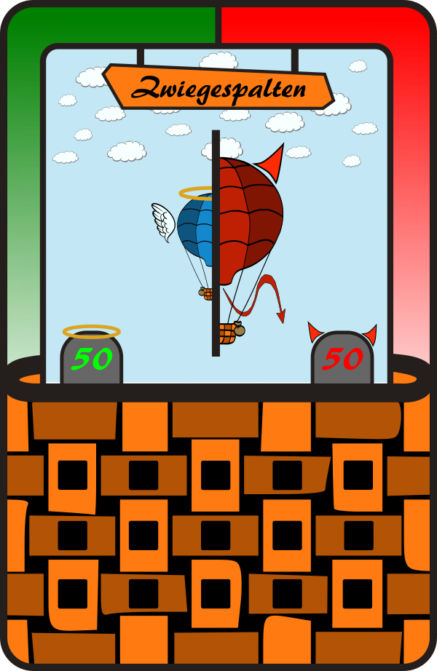
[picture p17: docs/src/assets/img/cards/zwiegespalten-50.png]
Zwiegespalten 50

<figcaption>Zwiegespalten 50</figcaption>
</figure>
<figure markdown="span">
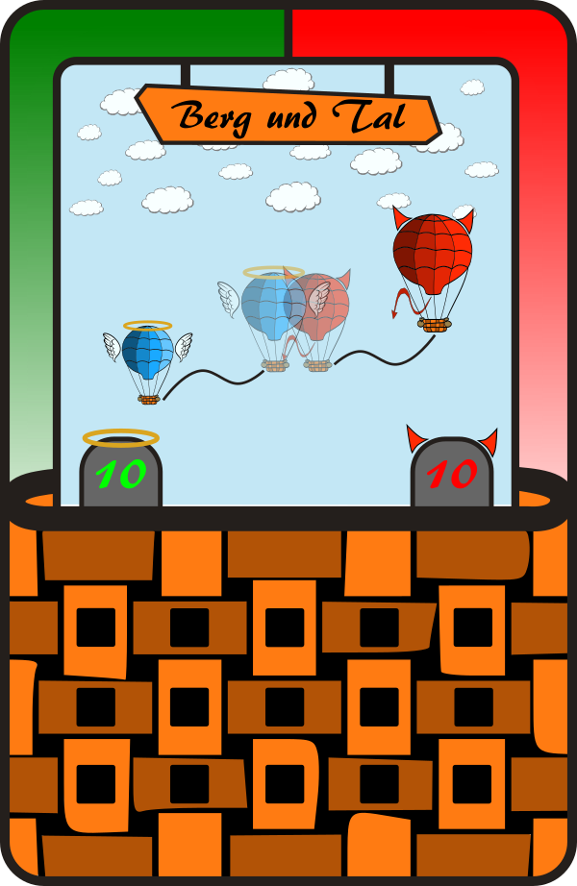
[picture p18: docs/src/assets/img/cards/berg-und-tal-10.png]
Berg und Tal 10

<figcaption>Berg und Tal 10</figcaption>
</figure>
<figure markdown="span">
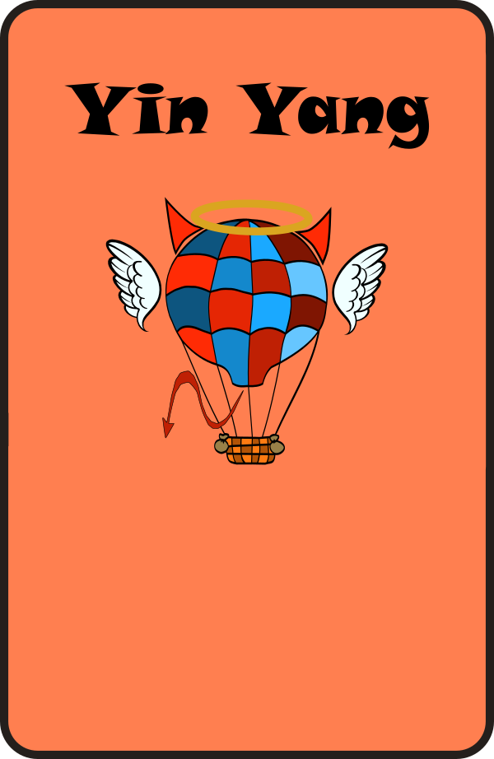
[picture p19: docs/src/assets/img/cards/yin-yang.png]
Yin Yang

<figcaption>Yin Yang</figcaption>
</figure>
</div>

### Player cards

<div class="card-grid" markdown>
<figure markdown="span">
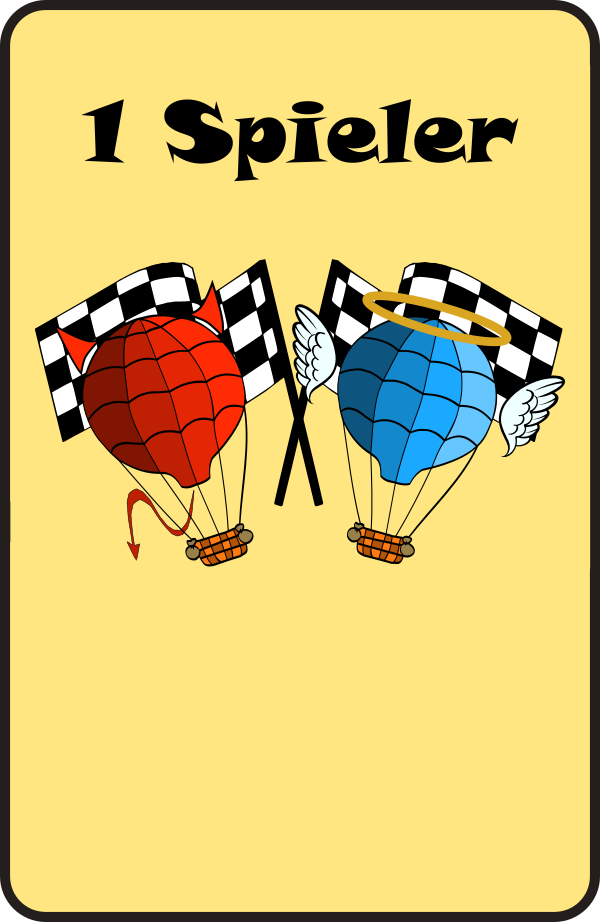
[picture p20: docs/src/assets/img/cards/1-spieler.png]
1 Spieler

<figcaption>1 Spieler</figcaption>
</figure>
<figure markdown="span">
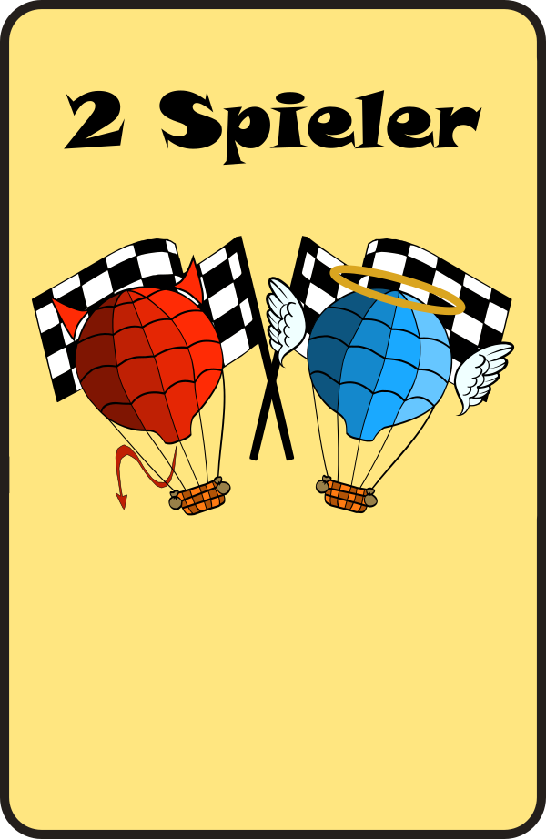
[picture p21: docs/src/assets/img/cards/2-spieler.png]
2 Spieler

<figcaption>2 Spieler</figcaption>
</figure>
<figure markdown="span">
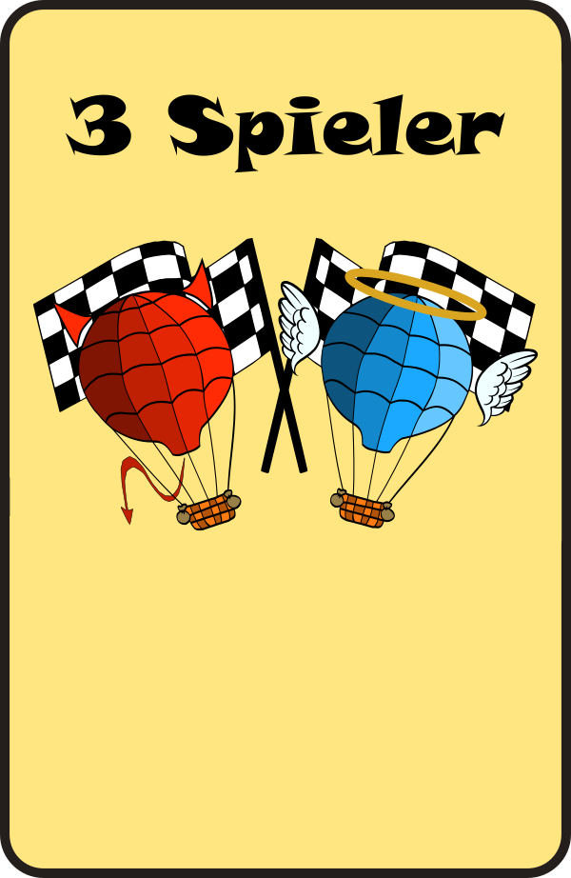
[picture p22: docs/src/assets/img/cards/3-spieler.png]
3 Spieler

<figcaption>3 Spieler</figcaption>
</figure>
<figure markdown="span">
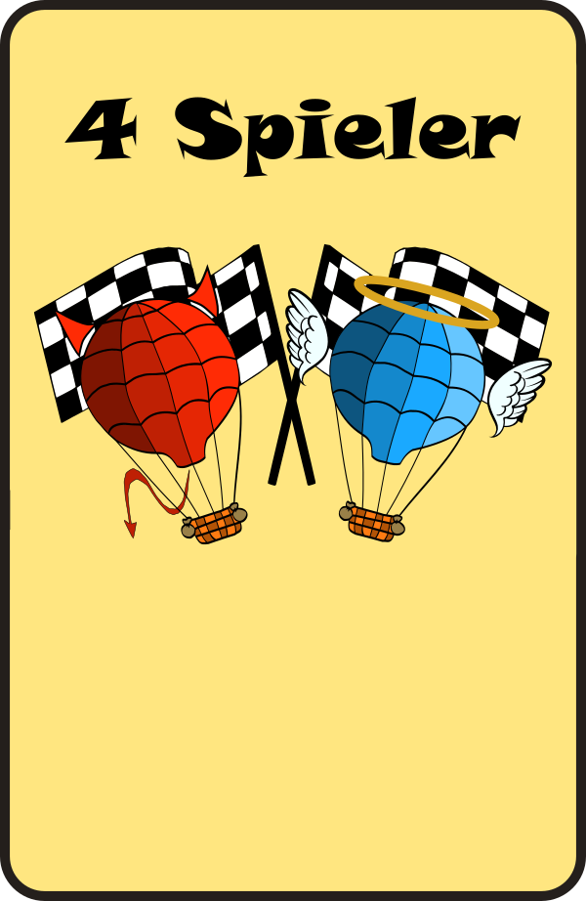
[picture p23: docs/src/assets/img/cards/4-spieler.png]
4 Spieler

<figcaption>4 Spieler</figcaption>
</figure>
<figure markdown="span">
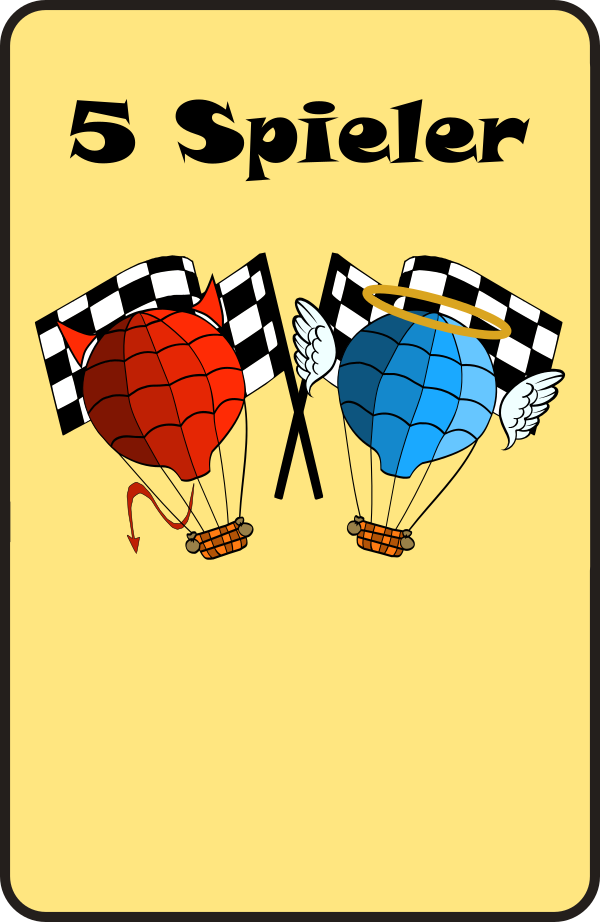
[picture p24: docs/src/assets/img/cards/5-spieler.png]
5 Spieler

<figcaption>5 Spieler</figcaption>
</figure>
</div>

### Others

<div class="card-grid" markdown>
<figure markdown="span">
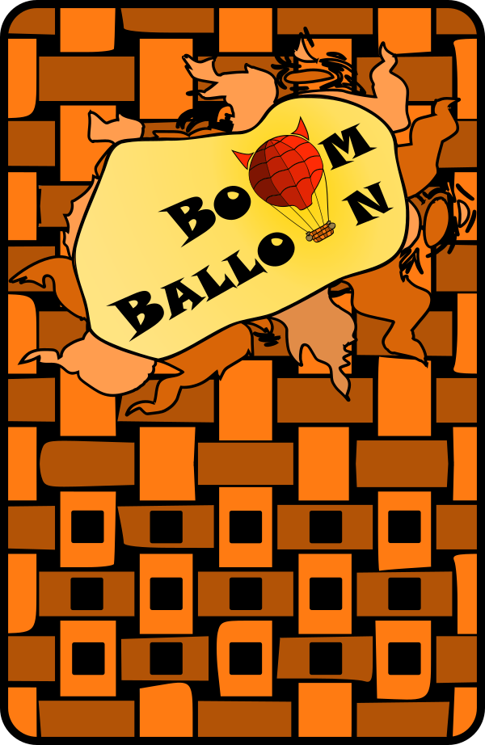
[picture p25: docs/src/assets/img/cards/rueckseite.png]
Card back

<figcaption>card back side</figcaption>
</figure>
<figure markdown="span">
Spielerkarte
<figcaption>player card back side</figcaption>
</figure>
<figure markdown="span">
Moduswechsel
<figcaption>Moduswechsel</figcaption>
</figure>
</div>

## What a card is

Every card is a printed rectangle with a machine-readable hole pattern:

- **Physical size:** 90 × 60 × 1 mm.
- **Holes:** 3 mm in diameter, spaced 10 mm apart.
- **Code:** 5 hole positions, so each card carries a **5-bit optical code** (a hole present or absent at each position). The card reader scans this pattern as the card slides in. See the [Optical Code System](../reference/optical-codes.md) reference for the bit layout and mirror-handling rules.

## The catalog

| German name | English gloss | Code | Effect | Count |
|---|---|---|---|---|
| Hochdruckgebiet 10 | High-pressure zone (deflate) | 1 | Deflates the balloon by 10 units. | 6 |
| Hochdruckgebiet 20 | High-pressure zone | 2 | Deflates the balloon by 20 units. | 6 |
| Kurswechsel 30 ↓ | Change of course (down) | 3 | Deflates the balloon by 30 units and reverses the direction of play. | 4 |
| Engelsbote 30 | Angel's messenger | 4 | Deflates the balloon by 30 units, but only at the start of the next round. | 3 |
| Blockierung | Blocking / miss round | 5 | The targeted player has a coin-flip chance of missing their turn. | 2 |
| Tiefdruckgebiet 10 | Low-pressure zone (inflate) | 6 | Inflates the balloon by 10 units. | 6 |
| Tiefdruckgebiet 20 | Low-pressure zone | 7 | Inflates the balloon by 20 units. | 6 |
| Kurswechsel 30 ↑ | Change of course (up) | 9 | Inflates the balloon by 30 units and reverses the direction of play. | 4 |
| Teufelsbote 30 | Devil's messenger | 10 | A coin-flip chance of a sudden, dangerous inflate of 30 units. | 3 |
| Weltuntergang | Apocalypse | 11 | Repeatedly inflates the balloon toward its bursting point. | 2 |
| Zwiegespalten 50 | Torn / fifty-fifty | 13 | A coin flip decides whether the balloon inflates or deflates by 50 units. | 3 |
| Berg und Tal 10 | Up hill and down | 14 | Repeatedly inflates and deflates the balloon by 10 units. | 3 |
| Yin Yang | Yin & Yang | 27 | Inflates the balloon almost all the way to its bursting point. | 1 |
| 1–5 Spieler | Player 1–5 | 15/17/19/21/23 | Picks a player as a target, or sets the game size at startup. | 1 each |

## Deck total and the player cards

The full deck is **about 54 cards**: **49 effect cards** (the play cards, or *Spielkarten*) plus **5 player cards** (*Spielerkarten*), for **54** in total.

The player cards, **`1 Spieler`…`5 Spieler`**, do two jobs:

- During play they act as **target cards** — you insert one to choose which player a target-based card (Teufelsbote, Blockierung, Weltuntergang) affects.
- The **`2 Spieler`…`5 Spieler`** cards additionally **choose the game size** when inserted at startup (see [Rules → Setting up a game](rules.md#setting-up-a-game)).

The **Yin Yang** card is a rare single wildcard that pushes the modelled volume all the way to the limit.

!!! info "The Moduswechsel card"
    The **Moduswechsel** ("mode change") card shown under [Others](#others) is not wired to any optical code and has no effect in the shipped firmware — inserting it does nothing. It's the leftover artwork for an unbuilt **game-mode selector**, originally meant to let players cycle through four play modes before starting a round. That feature was specced but never implemented; see [Firmware Architecture → The unbuilt mode system](../reference/firmware-architecture.md#the-unbuilt-mode-system) for the full history, including how code 27 ended up going to the **Yin Yang** card's one-shot `PushToLimitCard` instead.

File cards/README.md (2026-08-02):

# Cards

This folder holds the Boom Balloon card assets, plus pointers to the
authoritative card documentation.

## Contents

- **`artwork/`** — the printed card artwork: the Inkscape SVG masters
  (`Alle Karten 2.svg`, and `muster.svg` for the hole pattern) and the
  combined print sheets for the effect, player, and Yin-Yang decks.
- **`fonts/`** — the fonts the card SVGs reference. These must be installed
  on your system for the artwork to render correctly (see below).

## Fonts

The card artwork uses three non-standard fonts that ship with this folder:

| File | Font family (as referenced in the SVG) |
| --- | --- |
| `fonts/ARBERKLEY.ttf` | `AR BERKLEY` |
| `fonts/SNAP____.TTF` | `Snap ITC` |
| `fonts/Bell MT Regular.otf` | `Bell MT` |

Without them installed, Inkscape (or any SVG renderer) substitutes a fallback
font and the card layout will look wrong.

### Installing

**Linux**

```sh
mkdir -p ~/.local/share/fonts
cp cards/fonts/*.ttf cards/fonts/*.TTF cards/fonts/*.otf ~/.local/share/fonts/
fc-cache -f
```

**macOS** — double-click each file in `cards/fonts/` and click *Install Font*,
or copy them into `~/Library/Fonts/`.

**Windows** — select both files in `cards\fonts\`, right-click, and choose
*Install*.

After installing, reopen the SVGs in `artwork/` and confirm the text renders
in the correct fonts.

## Deck catalog & optical codes

The full **deck catalog** (every card's German name, English gloss, printed
face value, optical code, firmware effect, and deck count) and the **5-bit
optical code system** (bit weights, mirror invariance, sentinels) are the
single source of truth in the documentation site — this folder does not
duplicate them:

- **Deck catalog** → *Gameplay → The Card Deck* — [`docs/gameplay/card-deck.md`](../docs/gameplay/card-deck.md)
- **Optical code system** → *Reference → Optical Code System* — [`docs/reference/optical-codes.md`](../docs/reference/optical-codes.md)

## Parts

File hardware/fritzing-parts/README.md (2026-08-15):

# hardware/fritzing-parts/

Custom Fritzing parts (`.fzpz`) for BoomBalloon's own PCBs, so they can be dragged into
a Fritzing sketch like any other part instead of only existing as standalone board
designs. Generated by `media/pcb/parts/generate_<board>.py` from the board's real
Gerber data -- see `media/CLAUDE.md` for how.

To use: in Fritzing, drag a `.fzpz` file from this folder onto the canvas (or
File > Open it once to install it into your parts bin). Each part's breadboard-view
graphic is the real photorealistic PCB render; its connector pins are placed at the
real header positions, labeled with the same pin names used in
`docs/src/build-guide/wiring.md`.

`Steuermodul.fzpz` is the bare control board -- no Arduino baked in on purpose. Drag
Fritzing's own stock "Arduino Micro" part on top and position it by eye: the board
image is at the same true physical scale as every other part here, and the real PCB's
Arduino footprint was manufactured to fit a real Arduino Micro, so it should line up
exactly. (`hardware/control/Steuermodul.fzz` is still the one with the Arduino and the
TIP120 driver circuit already placed and wired, if you want that level of detail
instead -- see `hardware/system-wiring/BoomBalloon-Wiring.fzz`, which reuses it wholesale.)

See `hardware/system-wiring/BoomBalloon-Wiring.fzz` for a starter sketch with everything
already placed.

## Adding hand-drawn artwork

Each board's breadboard-view graphic is the real bare-PCB photo, which doesn't show
what a populated component actually looks like (an LED, a lit 7-segment digit, etc.).
Drop a transparent PNG named `<Board>_overlay.png` into `media/pcb/parts/overlays/`
(same pixel dimensions as the board's PNG in `docs/src/assets/img/`) and re-run
`generate_<board>.py` -- it's composited on top automatically. All four boards
currently have overlays.

## Fotomodul's "Connector" pass-through

`Fotomodul.fzpz` has 15 connectors: `FM` 7-pin, `LM` 2-pin, and `Connector` 6-pin --
the pass-through for the Displaymodul cable that `docs/src/build-guide/modules/card-reader.md`
documents and that's visibly present on the real assembled boards
(`docs/src/assets/img/gallery/fotomodul-assembled.jpg`). This used to be a known gap
(the component was missing from `hardware/card-reader/Kartenleser_Fotomodul.fzz`, so
there was no Gerber data to place it from) -- fixed 2026-08-14 when the source sketch
was corrected to include it. `Connector`'s 6 pins carry the same signals in the same
order as Displaymodul's own header (a straight pass-through), per
`docs/src/build-guide/modules/display.md`.

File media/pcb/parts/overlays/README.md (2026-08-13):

# overlays/

Optional hand-drawn artwork layered on top of a board's breadboard-view PNG when
building its custom Fritzing part -- e.g. a lit-looking 7-segment digit for
Displaymodul, since the real board photo just shows the bare component footprint.

Drop a file named `<Board>_overlay.png` here (e.g. `Displaymodul_overlay.png`) and
re-run `python3 media/pcb/parts/generate_<board>.py` -- it's picked up automatically
if present, skipped if not.

Requirements:
- **Exact same pixel dimensions** as `docs/src/assets/img/<board>-pcb-top.png`
  (the base image it's layered onto). `build_part.py` errors out if the sizes
  don't match, rather than silently misaligning the artwork.
- Transparent everywhere it isn't adding detail, so the real board photo shows
  through underneath.

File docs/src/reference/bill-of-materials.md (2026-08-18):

# Bill of Materials

This table is the authoritative BOM for the electronics described in the
[Build Guide overview](../build-guide/overview-bom.md). Part numbers and
suppliers below were reconciled against the original order sheet
([`hardware/bom/20170825_Bestellliste.xlsx`](https://github.com/boomballoon/boomballoon.github.io/blob/main/hardware/bom/20170825_Bestellliste.xlsx),
supplier mostly Reichelt). Datasheets for the numbered parts live under
[`hardware/datasheets/`](https://github.com/boomballoon/boomballoon.github.io/tree/main/hardware/datasheets).

| Component | Role | Qty | Part / supplier |
|---|---|---|---|
| Arduino Nano (ATmega328P) | Controller | 1 | Keywish Nano (original prototype used an Arduino Micro) |
| 12 V / 3 A PSU | Power | 1 | generic (Amazon) |
| DC socket (switched) | Power input | 1 | BKL 072342 |
| Toggle switch | On/off | 1 | MS-165 series |
| Membrane/vacuum pump | Inflate | 1 | AIRPO D2028B (12 V) |
| Solenoid valve | Deflate | 1 | CEME 5000EN1,5P |
| TIP120 Darlington | Pump/valve switching | 2 | STM (Reichelt) |
| 1N4004 diode | Flyback across each coil | 2 | — |
| 2.2 kΩ resistor | Transistor base | 2 | metal film (METALL 2,20K) |
| 74HC595 | Display shift register | 1 | SMD HC 595 |
| 7-seg 20 mm (common cathode) | Display digit | 1 | SC08-11 |
| Piezo buzzer | Audio | 1 | EKULIT AL-60P12 |
| Photoresistor | Card sensing | 5 | Reichelt A 905014 |
| 330 Ω resistor | Photocell divider (Fotomodul) | 5 | SMD 1206 |
| 3 mm LED | Card illumination | 5 | Reichelt LED EL 3-11250KW |
| 330 Ω resistor | LED limiting (Lichtmodul) | 5 | SMD 1206 |
| 330 Ω resistor | Segment limiting (Display) | 8 | SMD 1206 |
| Headers / stacking strips | Inter-module connectors | — | MPE-Garry / STAPELLEISTE (Reichelt) |
| Polycarbonate window | Display pane | 1 | Reely (Conrad 229802) |
| 3D-printed housing | Enclosure | 1 set | see [Enclosure](../build-guide/enclosure/index.md) |

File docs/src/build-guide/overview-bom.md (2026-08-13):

# System Overview

At the centre of the device is an **Arduino Nano** (ATmega328P). Three
electronic [modules](modules/index.md) plug into it, and everything lives
inside a 3D-printed housing:

1. The [**card reader**](modules/card-reader.md) optically senses which card is
   inserted. Five 3 mm LEDs (the *Lichtmodul*, light module) shine through the
   card onto five photoresistors (the *Fotomodul*, photo module); the pattern
   of light/dark spots encodes a 5-bit card value on analog inputs `A0`–`A4`.
2. The [**control board**](modules/control-board.md) (*Steuermodul*) is the
   physical hub. The Arduino sits on it, and two TIP120 Darlington channels
   switch the 12 V loads: a membrane pump that **inflates** the balloon and a
   solenoid valve that **deflates** it. The card-reader and display connectors
   also land here.
3. The [**display**](modules/display.md) (*Displaymodul*) is a single 20 mm
   7-segment digit driven by a 74HC595 shift register, plus a piezo buzzer for
   game sounds.
4. The [**enclosure**](enclosure/index.md) holds the balloon, the display
   window, the card slot, and the pump/valve mounts.

Power comes from a single **12 V / 3 A** supply. The 12 V rail feeds the pump
and valve; the Arduino derives the 5 V logic rail; the card-reader's *Fotomodul*
runs at **3.3 V** for a stable analog reference. The exact pin assignments are
on the [wiring](wiring.md) page — the authoritative source for
all connections.

For how the software drives all this during play, see
[How It Works](../how-it-works.md); for the card encoding scheme, see the
[Optical Code System](../reference/optical-codes.md); for the full parts
list, see the [Bill of Materials](../reference/bill-of-materials.md).

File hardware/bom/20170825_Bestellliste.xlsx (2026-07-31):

Anzahl Spiele: | 3
Platine | Bauteil | Artikelnummer | Datenblätter | Firma | Anzahl | Stückpreis | Anzahl Spiele | Gesamtkosten
Fotomodul | Fotodiode | A 905014 (https://www.reichelt.de/Fotodioden-etc-/A-905014/3/index.html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) | 20170825_Datenblätter\A90xxxx#PE.pdf | Reichelt | 5 | 1.25 € | 15 | 18.75 €
Fotomodul | Widerstand | SMD 1/4W 330 (https://www.reichelt.de/SMD-1206-von-0-bis-910-Ohm/SMD-1-4W-330/3/index.html?ACTION=3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) | 20170825_Datenblätter\SMD_1206.pdf | Reichelt | 5 | 0.03 € | 15 | 0.45 €
Fotomodul | Stiftleiste, gerade | MPE 087-1-050 (https://www.reichelt.de/Stiftleisten/MPE-087-1-050/3/index.html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) | 20170825_Datenblätter\DS_MPE_087.pdf | Reichelt | 1 | 0.87 € | 3 | 2.61 €
Fotomodul | Besondere Stiftleiste | STAPELLEISTE 10 (https://www.reichelt.de/Stiftleisten/STAPELLEISTE-10/3/index.html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) | 20170825_Datenblätter\STAPELLEISTE_XX.pdf | Reichelt | 2 | 0.44 € | 6 | 2.64 €
 |  |  |  |  |  |  | 0 | 0.00 €
Lichtmodul | LED | LED EL 3-11250KW (https://www.reichelt.de/LEDs-3-mm/LED-EL-3-11250KW/3/index.html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) | 20170825_Datenblätter\204-15UTC-S400-X9-L_V2.pdf | Reichelt | 5 | 0.24 € | 15 | 3.60 €
Lichtmodul | Widerstand | SMD 1/4W 330 (https://www.reichelt.de/SMD-1206-von-0-bis-910-Ohm/SMD-1-4W-330/3/index.html?ACTION=3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) | 20170825_Datenblätter\SMD_1206.pdf | Reichelt | 5 | 0.03 € | 15 | 0.45 €
Lichtmodul | Buchsenleiste | MPE 094-1-016 (https://www.reichelt.de/Buchsenleisten/MPE-094-1-016/3/index.html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) | 20170825_Datenblätter\DS_MPE_094.pdf | Reichelt | 1 | 0.31 € | 3 | 0.93 €
 |  |  |  |  |  |  | 0 | 0.00 €
Steuermodul | Transistor | TIP 120 STM (https://www.reichelt.de/TIP-J-Transistoren/TIP-120-STM/3/index.html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) | 20170825_Datenblätter\TIP120_TIP121_TIP122_TIP125_TIP126_TIP127#STM.pdf | Reichelt | 2 | 0.28 € | 6 | 1.68 €
Steuermodul | Präz. Buchsenleiste | MPE 115-1-036 (https://www.reichelt.de/Buchsenleisten/MPE-115-1-036/3/index.html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) | 20170825_Datenblätter\DS_MPE_115.pdf | Reichelt | 1 | 1.99 € | 3 | 5.97 €
Steuermodul | Widerstand | METALL 2,20K (https://www.reichelt.de/0-6W-1-1-00-k-Ohm-9-76-k-Ohm/METALL-2-20K/3/index.html?ACTION=3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) | 20170825_Datenblätter\METALL#YAG.pdf | Reichelt | 2 | 0.08 € | 6 | 0.49 €
Steuermodul | Diode | 1N 4004 (https://www.reichelt.de/1N-UF-AA-Dioden/1N-4004/3/index.html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) | 20170825_Datenblätter\1N400x_FAI.pdf | Reichelt | 2 | 0.04 € | 6 | 0.24 €
Steuermodul | Jumper, schwarz | JUMPER 2,54GL SW (https://www.reichelt.de/Stiftleisten/JUMPER-2-54GL-SW/3/index.html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) | 20170825_Datenblätter\JUMPER254GL#DIV.pdf | Reichelt | 3 | 0.02 € | 9 | 0.18 €
Steuermodul | Jumper, rot | JUMPER 2,54GL RT (https://www.reichelt.de/Stiftleisten/JUMPER-2-54GL-RT/3/index.html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) | 20170825_Datenblätter\JUMPER254GL#DIV.pdf | Reichelt | 3 | 0.04 € | 9 | 0.36 €
 |  |  |  |  |  |  | 0 | 0.00 €
Displaymodul | Summer | SUMMER AL-60P12 (https://www.reichelt.de/Signalakustik/SUMMER-AL-60P12/3/index.html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) | 20170825_Datenblätter\155120AL-60P12.pdf | Reichelt | 1 | 0.55 € | 3 | 1.65 €
Displaymodul | 7 Segment Anzeige | SC 08-11 RT (https://www.reichelt.de/Siebensegment-Anzeigen/SC-08-11-RT/3/index.html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) | 20170825_Datenblätter\SC08-11SRWA(V6).pdf | Reichelt | 1 | 1.15 € | 3 | 3.45 €
Displaymodul | Widerstand | SMD 1/4W 330 (https://www.reichelt.de/SMD-1206-von-0-bis-910-Ohm/SMD-1-4W-330/3/index.html?ACTION=3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) | 20170825_Datenblätter\SMD_1206.pdf | Reichelt | 8 | 0.25 € | 24 | 6.00 €
Displaymodul | Schaltkreis | SMD HC 595 (https://www.reichelt.de/ICs-74HC-SMD/SMD-HC-595/3/index.html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) | 20170825_Datenblätter\smd_hc_595.pdf | Reichelt | 1 | 0.20 € | 3 | 0.60 €
Displaymodul | Stiftleiste, gewinkelt | SL 1X50W 2,54 (https://www.reichelt.de/Stiftleisten/SL-1X50W-2-54/3/index.html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) | 20170825_Datenblätter\088-1-050-0-F-XS0-1080.pdf | Reichelt | 1 | 0.97 € | 3 | 2.91 €
 |  |  |  |  |  |  | 0 | 0.00 €
Netzteil |  | Netzteil 12V3A (https://www.amazon.de/dp/B01AA83VHA/ref=twister_B01N2B7MHX?_encoding=UTF8&psc=1) |  | Amazon | 1 | 9.99 € | 3 | 29.97 €
Netzbuchse |  | HEBLM 25 (https://www.reichelt.de/Hohlstecker/HEBLM-25/3/index.html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) |  | Reichelt | 1 | 0.81 € | 3 | 2.43 €
Ablassventil |  | Magnetventil (http://www.ebay.de/itm/Druckluft-Magnetventil-elektrisch-8-12V-Mini-Ventil-Modellbau-Pneumatik-/161404729688) |  | ebay | 1 | 6.28 € | 3 | 18.84 €
Vakuum Pumpe |  | AIRPO D2028B (https://www.electronic-shop.lu/DE/products/152670) | 20170825_Datenblätter\AIRPO D2028B.pdf | Electronic Shop | 1 | 20.60 € | 3 | 61.80 €
Arduino board | Arduino Micro | ARDUINO MICRO (https://www.reichelt.de/Einplatinen-Microcontroller/ARDUINO-MICRO/3/index.html?ACTION=3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) |  | Reichelt | 1 | 18.50 € | 3 | 55.50 €
Ein- und Ausschalter | Kippschalter Ein-Aus | MS 165 (https://www.reichelt.de/Kippschalter/MS-165/3/index.html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) | 20170825_Datenblätter\MS-165_169.pdf | Reichelt | 1 | 1.80 € | 3 | 5.40 €
Kabel | Jumper Wire | Steckbrücken (https://www.amazon.de/Elegoo-Female-Female-Male-Female-Steckbr%C3%BCcken-Drahtbr%C3%BCcken/dp/B01EV70C78?s=aps) |  | Amazon | 1 | 6.99 € | 3 | 20.97 €
Mikrofon | Arduino Soundmodul | Mikrofon-Sensor (https://www.amazon.de/Mikrofon-Sensor-Modul-analogem-digitalem-Ausgang-Sound-Detektor/dp/B01H7CNI70) |  | Amazon | 1 | 6.89 € | 3 | 20.67 €
Mikrofon | Soundfounder | Sensor Module (https://www.amazon.de/SunFounder-Sensor-Module-Arduino-Raspberry/dp/B013QR8ZT6)
Spielkarten
Bedienungsanleitung
Spielekarton | FantasyRoom (https://www.my-fantasyroom.de/boxensetballonspunktetiereblaugold175cm-p-51734.html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)
Klebefolien Kartonflächen
Gehäuse Bauteile
Kartenmodul |  | Vorabversion 2016 | rot | https://i.materialise.de/ | 1 | 75.96 € | 1 | 75.96 €
Gehäuse Oberteil |  |  | Braun poliert | https://i.materialise.de/ | 1 | 105.99 € | 3 | 317.97 €
Gehäuse Unterteil |  |  | Braun poliert | https://i.materialise.de/ | 1 | 133.89 € | 3 | 401.67 €
Kartenmodul |  |  | Orange poliert | https://i.materialise.de/ | 1 | 55.03 € | 3 | 165.09 €
Dach-Spitz |  |  | Rot poliert | https://i.materialise.de/ | 1 | 18.79 € | 3 | 56.37 €
Schlauch-Stutzen Oberteil |  |  | weiss poliert | https://i.materialise.de/ | 1 | 14.45 € | 3 | 43.35 €
Scheibe | 21,75 x 29,45 x 0,75 | Polycarbonat-Platte Reely (https://www.conrad.de/de/polycarbonat-platte-reely-l-x-b-400-mm-x-500-mm-075-mm-229802.html) | 400 x 500 x 0,75 | Conrad - 229802 - 62 | 1 | 6.99 € | 1 | 6.99 €
Gehäuse Bauteile |  |  |  | ZU TEUER
Kartenmodul |  | Vorabversion 2016 |  | Rapid Object (http://www.rapidobject.com/) | 1 | 75.96 € | 1 | 75.96 €
Gehäuse Oberteil |  |  |  | Rapid Object (http://www.rapidobject.com/) | 1 | 106.75 € | 3 | 320.25 €
Gehäuse Unterteil |  |  |  | Rapid Object (http://www.rapidobject.com/) | 1 | 142.28 € | 3 | 426.84 €
Kartenmodul |  |  |  | Rapid Object (http://www.rapidobject.com/) | 1 | 92.25 € | 3 | 276.75 €
Dach-Spitz |  |  |  | Rapid Object (http://www.rapidobject.com/) | 1 | 17.26 € | 3 | 51.78 €
Schlauch-Stutzen Oberteil |  |  |  | Rapid Object (http://www.rapidobject.com/) | 1 | 32.73 € | 3 | 98.19 €
Scheibe | 21,75 x 29,45 x 0,75 | Polycarbonat-Platte Reely (https://www.conrad.de/de/polycarbonat-platte-reely-l-x-b-400-mm-x-500-mm-075-mm-229802.html) | 400 x 500 x 0,75 | Conrad - 229802 - 62 | 1 | 6.99 € | 1 | 6.99 €
https://www.rapidobject.com/upload/#!upload

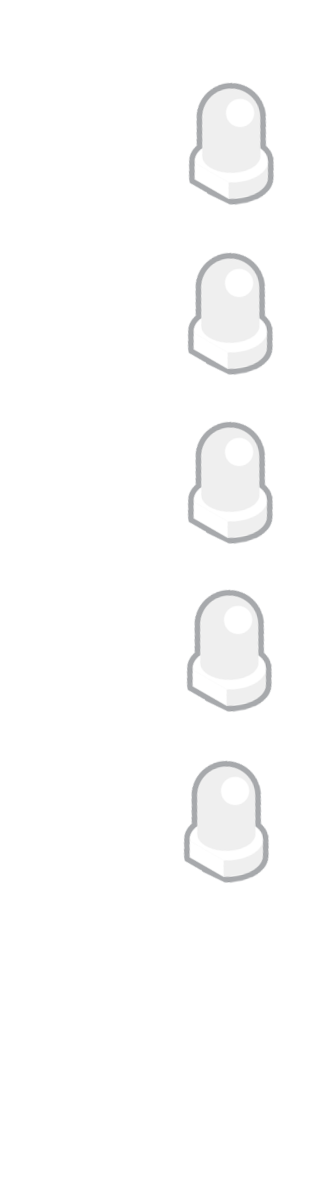
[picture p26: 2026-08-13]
media/pcb/parts/overlays/Lichtmodul_overlay.png

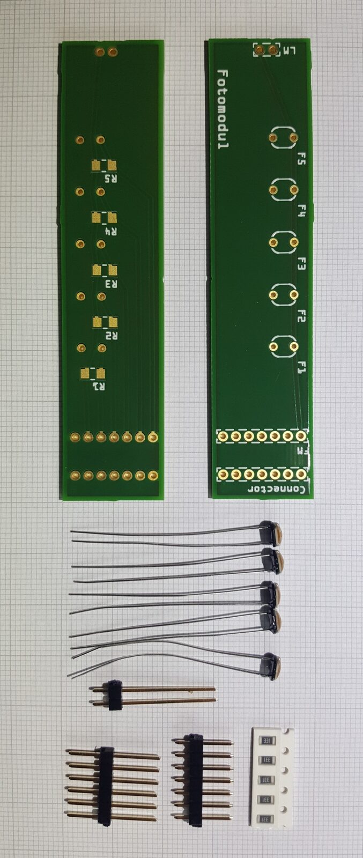
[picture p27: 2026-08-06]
media/gallery/fotomodul-parts.jpg

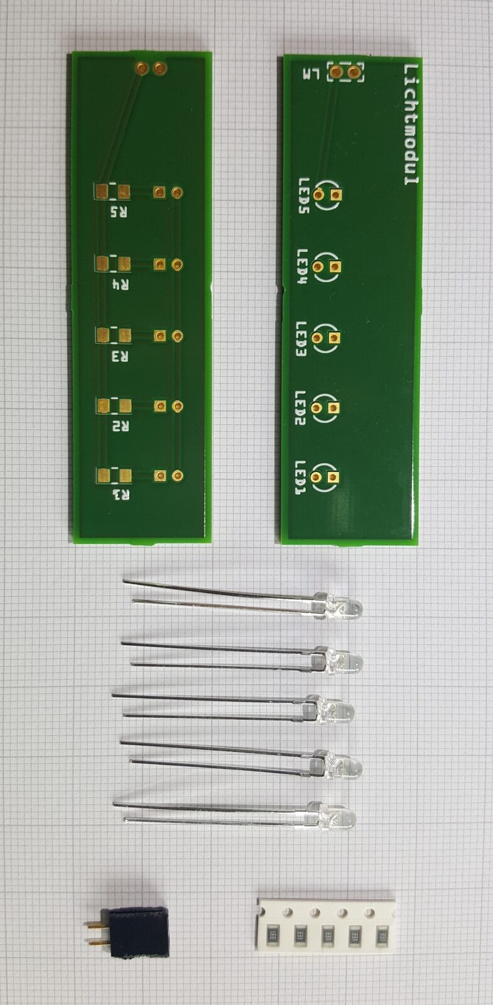
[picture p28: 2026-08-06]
media/gallery/lichtmodul-parts.jpg

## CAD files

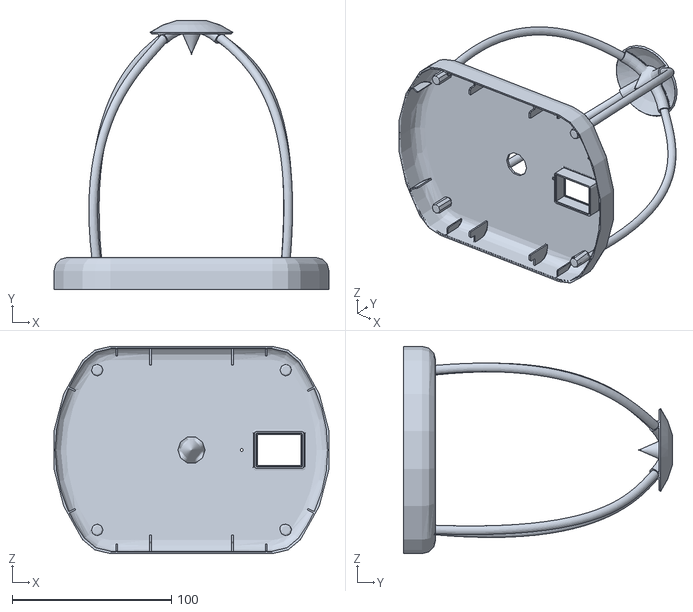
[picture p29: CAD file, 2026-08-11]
hardware/enclosure/stl/roof-assembly.stl
172.5 x 168.6 x 130.0

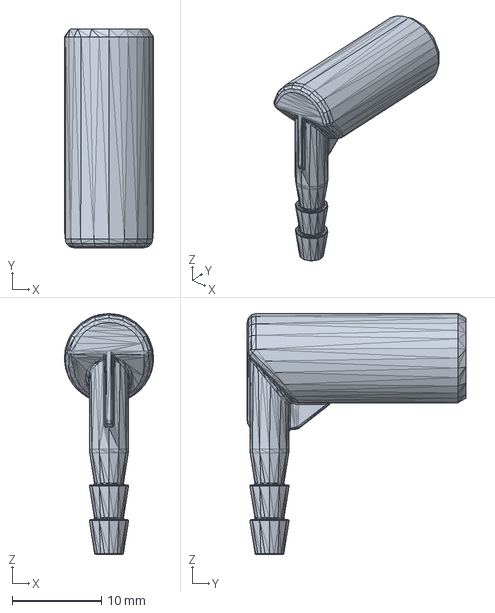
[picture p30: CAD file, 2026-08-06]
hardware/enclosure/step/hose-nozzle.stp
10.0 x 24.5 x 27.0 mm

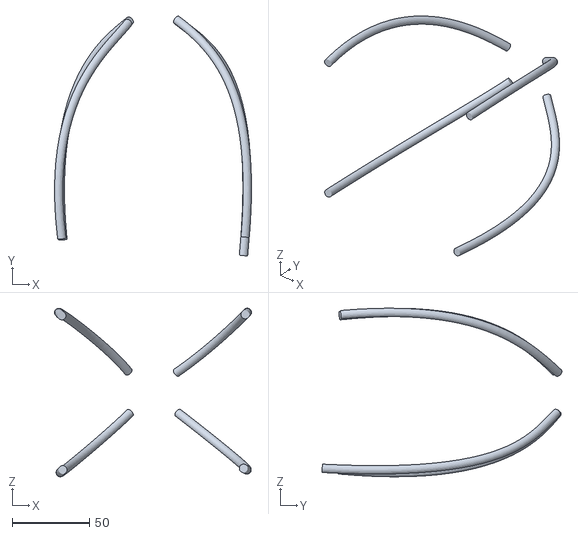
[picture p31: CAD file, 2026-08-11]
hardware/enclosure/stl/knicklichter.stl
127.8 x 155.5 x 109.4

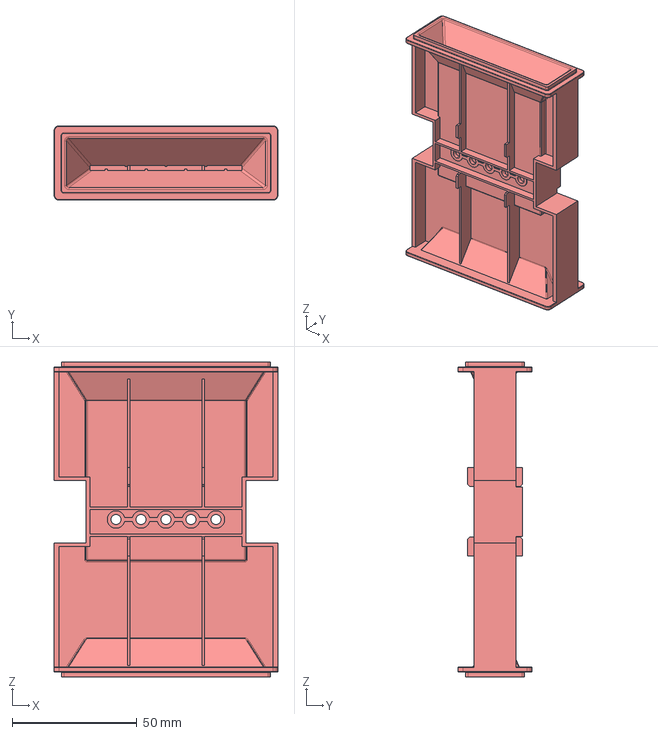
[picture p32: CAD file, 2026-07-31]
hardware/enclosure/step/card-module-housing.stp
89.6 x 29.7 x 126.0 mm

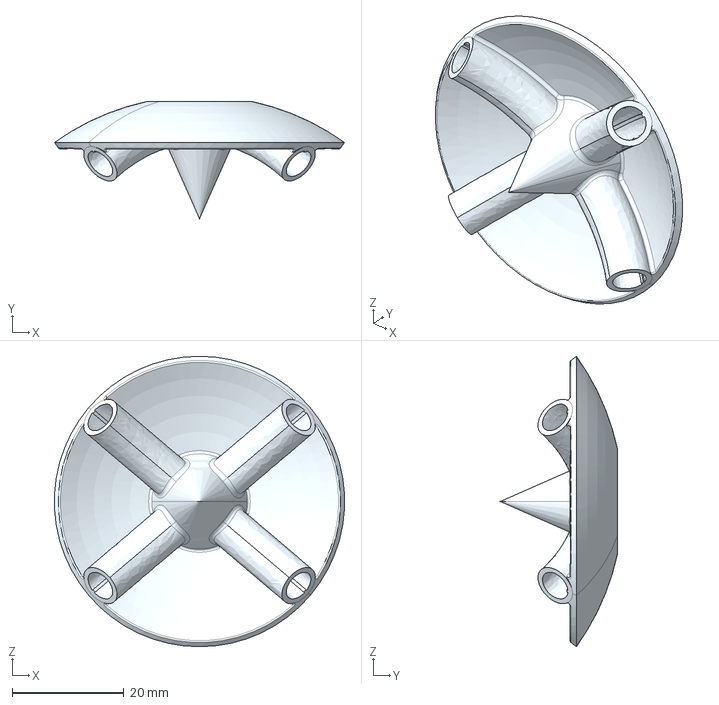
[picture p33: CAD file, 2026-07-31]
hardware/enclosure/step/roof.stp
52.0 x 21.0 x 52.0 mm

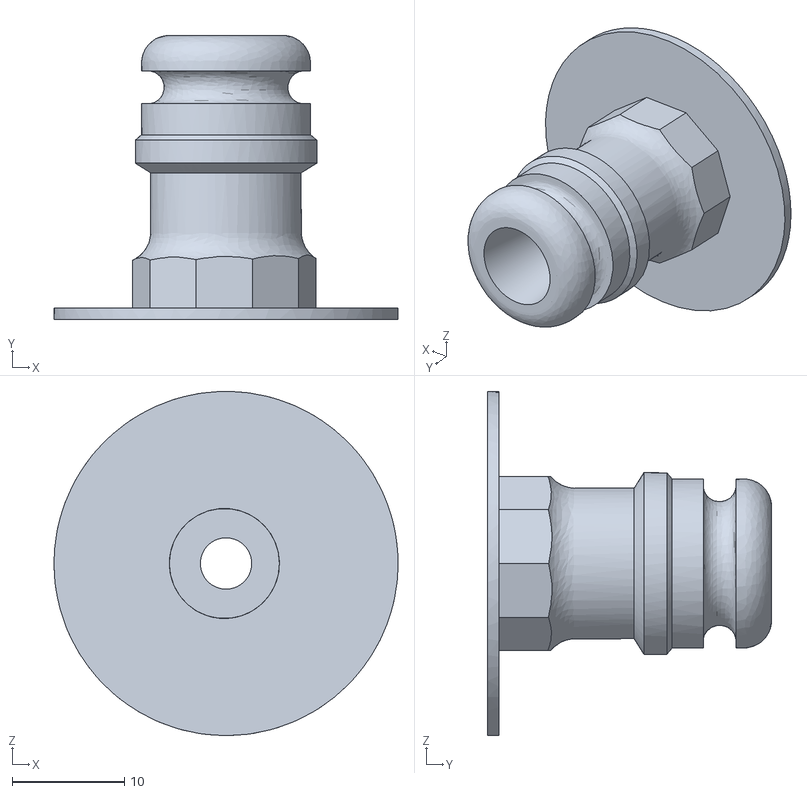
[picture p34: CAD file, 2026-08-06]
hardware/enclosure/stl/balloon-adapter.stl
30.6 x 25.3 x 30.6

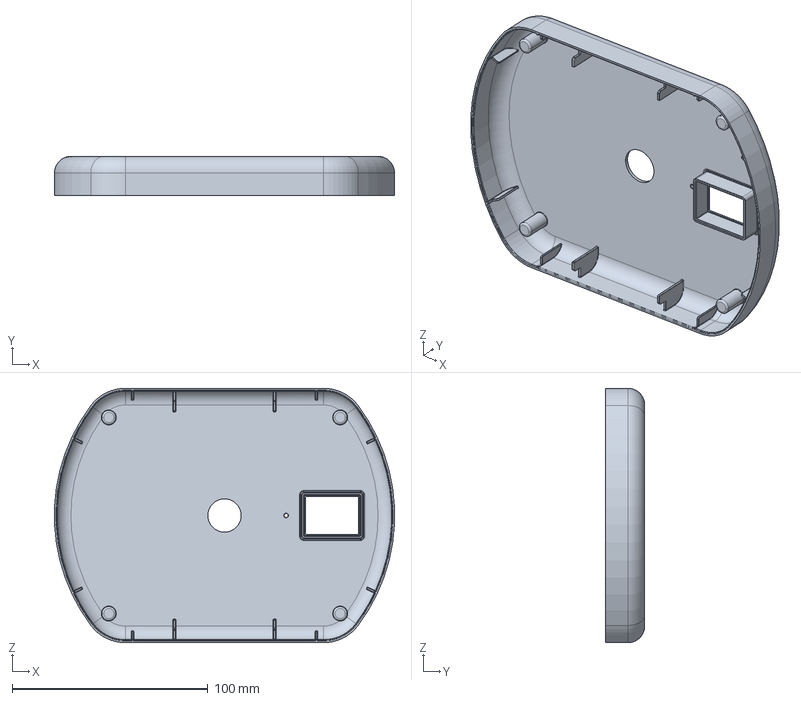
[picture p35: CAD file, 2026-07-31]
hardware/enclosure/step/upper-housing.stp
173.8 x 20.1 x 130.0 mm

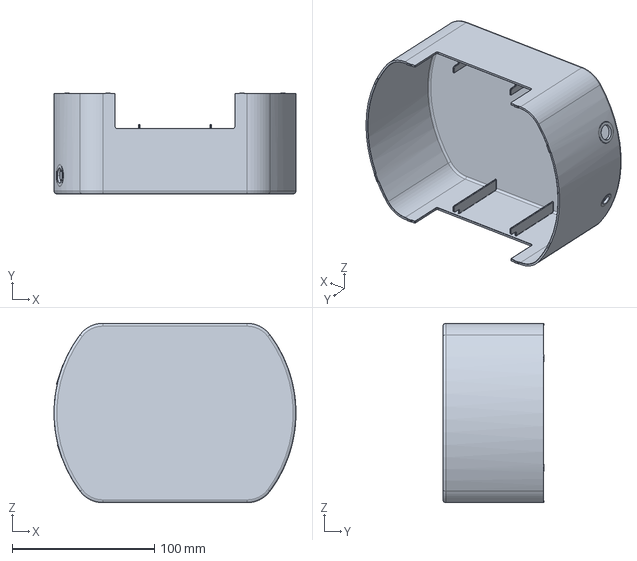
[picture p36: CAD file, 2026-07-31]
hardware/enclosure/step/lower-housing.stp
170.0 x 71.0 x 126.0 mm

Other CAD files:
hardware/enclosure/stl/card-module-housing.stl
hardware/enclosure/stl/hose-nozzle.stl
hardware/enclosure/stl/lower-housing.stl
hardware/enclosure/stl/roof.stl
hardware/enclosure/stl/upper-housing.stl
media/enclosure/roof-assembly.blend

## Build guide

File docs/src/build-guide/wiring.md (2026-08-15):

# Wiring

This page describes how the Arduino Nano on the control board connects to
everything else.

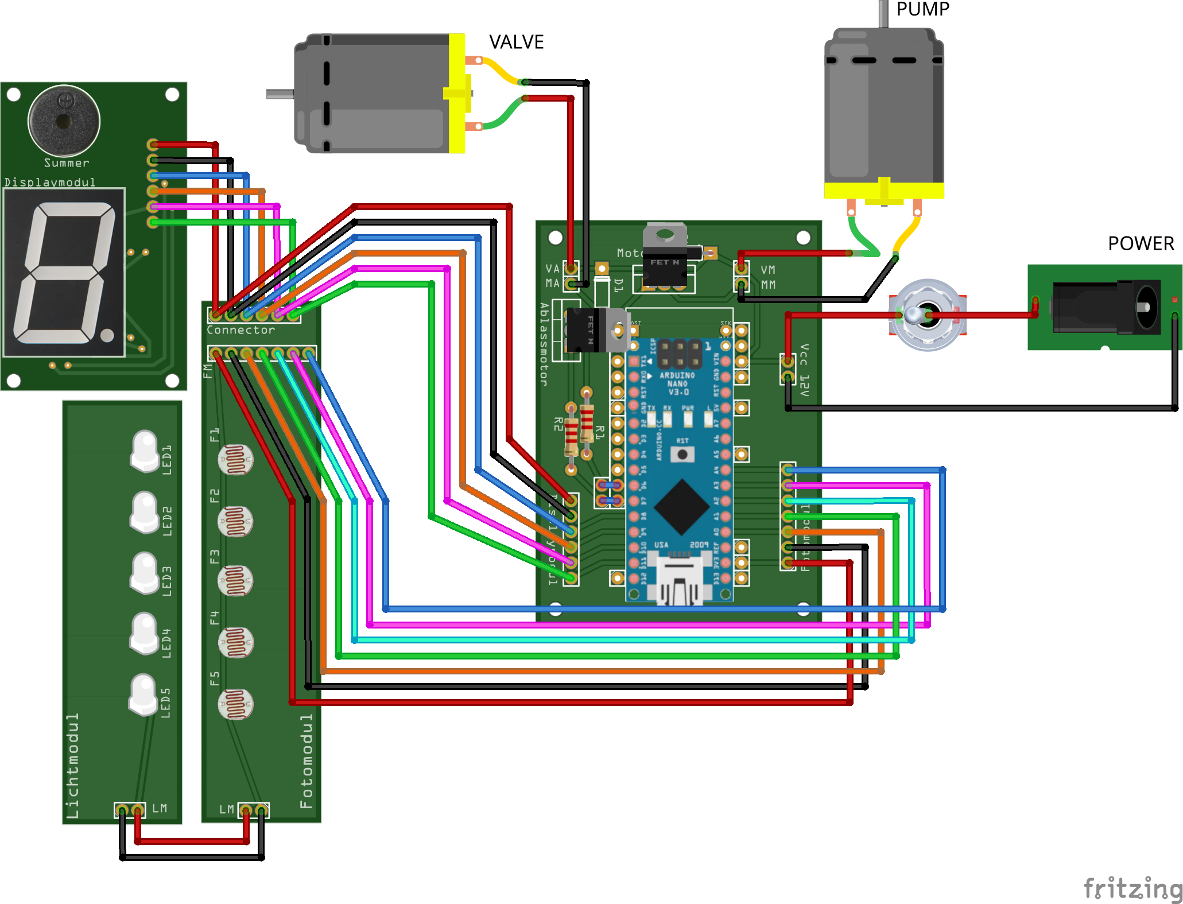
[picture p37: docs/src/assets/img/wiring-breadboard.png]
Breadboard-view wiring diagram: Displaymodul and Lichtmodul on the left feeding into Fotomodul, which connects to the Steuermodul/Arduino; the pump and valve motors, rotary switch, and power jack on the right.


## Master pin map

| Function | MCU pin | Dir | Connects to |
|---|---|---|---|
| Card reader bit 0 | A0 | in | Fotomodul 7-pin (pin 3) |
| Card reader bit 1 | A1 | in | Fotomodul 7-pin (pin 4) |
| Card reader bit 2 | A2 | in | Fotomodul 7-pin (pin 5) |
| Card reader bit 3 | A3 | in | Fotomodul 7-pin (pin 6) |
| Card reader bit 4 | A4 | in | Fotomodul 7-pin (pin 7) |
| Pump (inflate) | D6 | out | Steuermodul **MA/MM** → TIP120 → AIRPO pump |
| Valve (deflate) | D7 | out | Steuermodul **VA/VM** → TIP120 → CEME solenoid |
| Display data (DS) | D8 | out | Displaymodul pin 3 → 74HC595 serial data |
| Display latch (STCP) | D9 | out | Displaymodul pin 4 → 74HC595 storage clock |
| Display clock (SHCP) | D10 | out | Displaymodul pin 5 → 74HC595 shift clock |
| Buzzer | D11 | out | Displaymodul pin 6 → piezo buzzer |
| RNG seed | A5 | — | **must stay unconnected (floating)** |

!!! warning "Leave A5 floating"
    `A5` is deliberately **not connected**. The firmware reads its floating,
    noisy analog value to seed the random-number generator. Wiring it to
    anything would make the seed deterministic and hurt game randomness.

## Power

A single **12 V / 3 A** supply powers the whole device, entering through a
switched DC socket:

- **12 V rail** → the pump and the valve (switched by the two TIP120 channels on
  the [control board](modules/control-board.md)).
- **5 V logic rail** → derived on the Arduino; powers the Arduino itself and the
  [display module](modules/display.md) (74HC595 + buzzer).
- **3.3 V** → the [card reader's *Fotomodul*](modules/card-reader.md), for a
  stable analog reference on `A0`–`A4`.

## Where the connectors live

All three modules meet on the [control board](modules/control-board.md):

- **Fotomodul 7-pin** — 3.3 V, GND, and `A0`–`A4`
  (see the [card reader](modules/card-reader.md#fotomodul-connector-7-pin)).
- **Displaymodul 6-pin** — 5 V, GND, `DS`/`STCP`/`SHCP`, and buzzer
  (see the [display](modules/display.md#connector-6-pin)).
- **12 V input** and the pump/valve output terminals (`MA/MM`, `VA/VM`).

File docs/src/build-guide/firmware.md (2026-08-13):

# Firmware

The firmware targets the Arduino Nano (ATmega328P). It is a small OOP C++
source tree under `firmware/src/` (`Main.cpp` provides `setup()`/`loop()`;
headers are included root-relative, e.g. `#include <Cards/Card.h>`). The build
system is [PlatformIO](https://platformio.org/), which pins the toolchain and
Arduino core so a clean checkout builds identically everywhere. The canonical
reference is
[`firmware/README.md`](https://github.com/boomballoon/boomballoon.github.io/blob/main/firmware/README.md).

## Prerequisites

Install PlatformIO Core:

```bash
pip install platformio
```

## Build

```bash
cd firmware
pio run                       # builds all environments
pio run -e nanoatmega328      # just the Nano (the current board)
```

The compiled image is written to `.pio/build/<env>/firmware.hex`.

## Flash

Pick the environment that matches your board:

```bash
pio run -t upload -e nanoatmega328      # Arduino Nano, old bootloader (57600 baud)
pio run -t upload -e micro              # Arduino Micro (early-prototype board)
```

The project's Nanos are older clones with the old bootloader. If an upload
times out on a newer board, its bootloader expects 115200 baud — switch the
environment to `board = nanoatmega328new` in `platformio.ini`.

The `micro` environment targets the Arduino Micro (ATmega32U4) that ran the
2015–2018 prototypes (see
[the story](../story.md#the-controller-from-micro-to-nano)). The pin map is
unchanged since then, so a Micro still runs the current firmware.

PlatformIO auto-detects the serial port; force it with
`--upload-port /dev/ttyUSB0` (Linux CH340 clone), `/dev/ttyACM0` (genuine), or
`COMx` (Windows).

## Serial monitor

```bash
pio device monitor            # 9600 baud, matching Serial.begin(9600)
```

## Build switches

Compile-time switches live in `src/Constants.h`:

- **`AUTOSTART_GAME`** — auto-starts a 2-player game on boot, skipping the
  player-count detection flow. Handy for testing.
- **`MOCK_CODE_DETECTOR`** / **`MOCK_OUTPUT_DEVICE`** — swap in the serial mocks
  from `src/Mock/` in place of the real devices, so the game runs with missing
  hardware. The two are **independent** — mock one and keep the other real, or
  mock both:
    - **`MOCK_CODE_DETECTOR`** reads card codes from the serial console (type a
      code + `<enter>`) instead of the photoresistor card reader.
    - **`MOCK_OUTPUT_DEVICE`** prints the balloon volume to serial (a percentage
      and an ASCII bar) instead of driving the pump/valve.

    Pair them with `AUTOSTART_GAME` to boot straight into a game with no hardware
  attached (the `make mock`, `make mock-code`, and `make mock-output` targets
  wrap these):

  ```bash
  PLATFORMIO_BUILD_FLAGS="-D MOCK_CODE_DETECTOR -D MOCK_OUTPUT_DEVICE -D AUTOSTART_GAME" pio run -t upload -e nanoatmega328
  ```

- **`DETECTOR_CALIBRATION`** — replaces the game loop with a
  [card-reader](modules/card-reader.md) bring-up harness that prints raw
  photoresistor values. `<SPACE>` pauses output; `<TAB>` switches to
  changes-only output. Use it to pick card-reader thresholds.

  ```bash
  PLATFORMIO_BUILD_FLAGS="-D DETECTOR_CALIBRATION" pio run -t upload -e nanoatmega328
  ```

## See also

- [Wiring](wiring.md) — which pins the firmware drives.
- [Firmware Architecture](../reference/firmware-architecture.md) — how the code
  is organized.
- [`firmware/README.md`](https://github.com/boomballoon/boomballoon.github.io/blob/main/firmware/README.md)
  — the canonical build reference.

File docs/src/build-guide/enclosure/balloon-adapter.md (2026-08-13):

# Balloon Adapter

*Ballon-Aufsatz* — the balloon adapter that mounts on top of the
[upper housing](upper-housing.md).
The balloon is attached to the adapter and during game air is pumped through the adapter into the ballon.
The ballon then inflates until it hits the spike in the [roof](roof.md).

<div class="gallery" markdown="span">
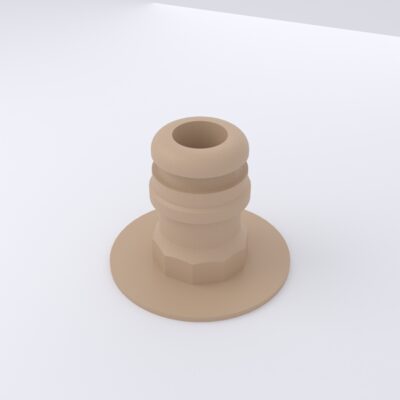
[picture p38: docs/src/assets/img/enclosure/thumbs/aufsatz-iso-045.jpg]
Balloon adapter — iso
{ .glightbox data-gallery="aufsatz" data-title="Balloon adapter — iso" }
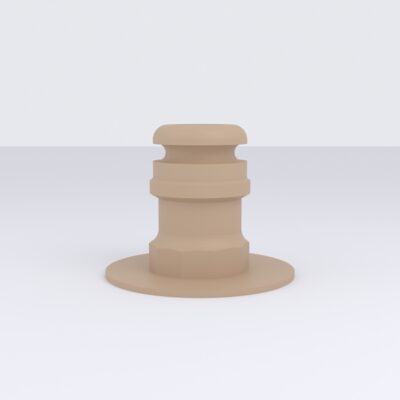
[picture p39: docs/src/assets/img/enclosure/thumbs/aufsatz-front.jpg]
Balloon adapter — profile (barbs)
{ .glightbox data-gallery="aufsatz" data-title="Balloon adapter — profile (barbs)" }
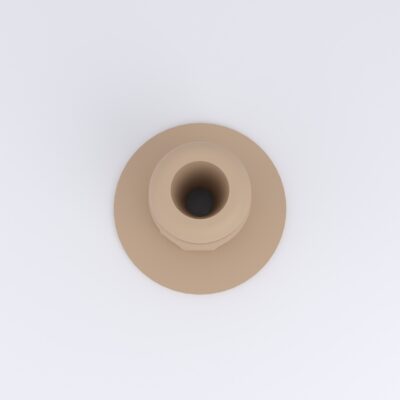
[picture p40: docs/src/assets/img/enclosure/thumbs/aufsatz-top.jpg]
Balloon adapter — top (bore)
{ .glightbox data-gallery="aufsatz" data-title="Balloon adapter — top (bore)" }
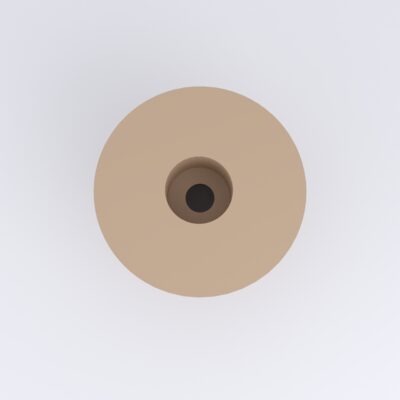
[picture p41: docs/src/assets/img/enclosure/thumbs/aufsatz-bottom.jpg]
Balloon adapter — underside (flange)
{ .glightbox data-gallery="aufsatz" data-title="Balloon adapter — underside (flange)" }
</div>

**Bounding box:** ≈ ⌀32 × 25 mm (round flange diameter × height).

## Interior

A section down the centreline shows the through-bore: the wide seat at the top
where the balloon sits, the barb ridges that grip it, and the counterbored
inlet under the flange. The second section adds the [hose nozzle](nozzle.md) in
its assembled position, so the full air path is visible — from the balloon seat,
down the adapter bore, through the nozzle elbow, and out to the barbed tubing
fitting.

<div class="board-pair" markdown>
<figure markdown="span">
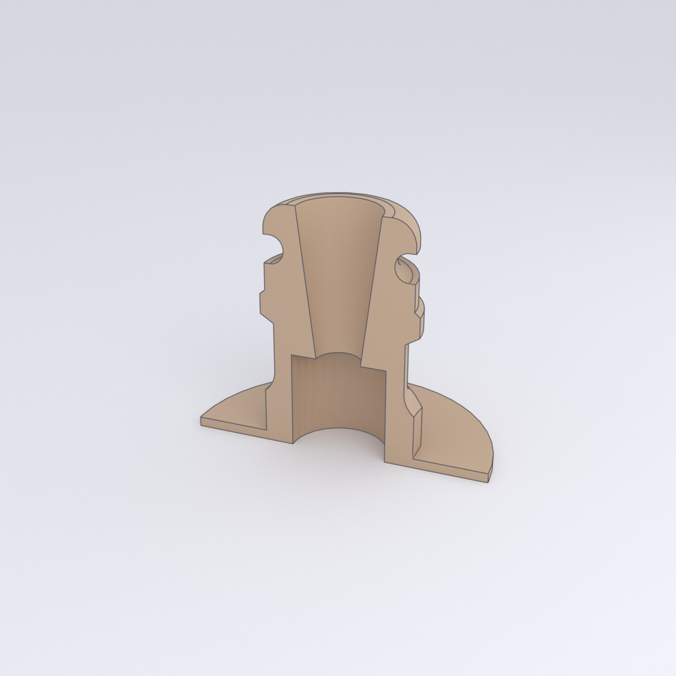
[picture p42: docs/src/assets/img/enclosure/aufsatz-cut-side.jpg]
Balloon adapter — side cut

<figcaption>Side cut — through the bore, barbs, and mounting flange</figcaption>
</figure>
<figure markdown="span">
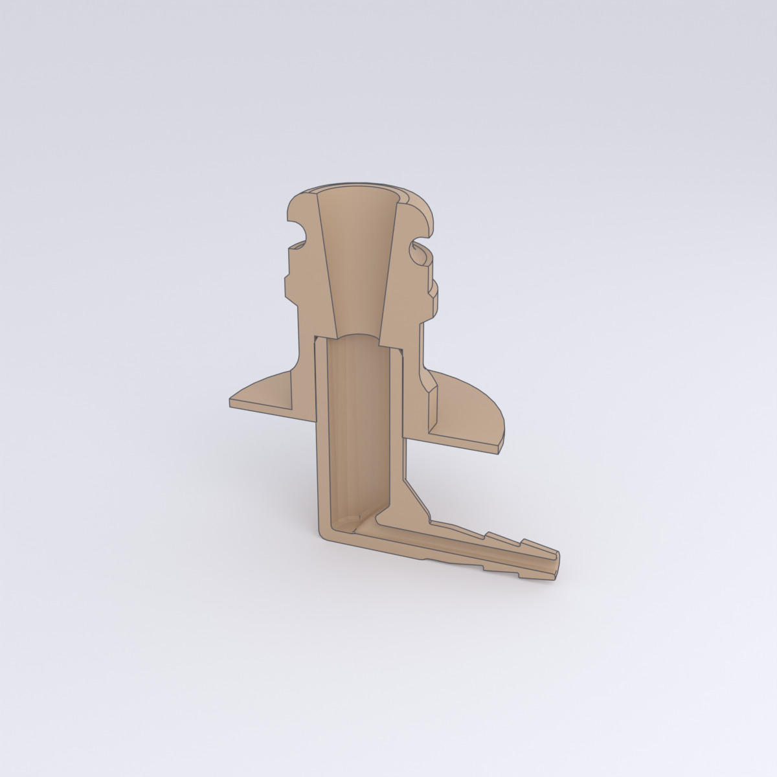
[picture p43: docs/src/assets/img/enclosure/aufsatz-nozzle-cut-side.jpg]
Adapter and nozzle — side cut

<figcaption>Adapter + nozzle — the continuous bore through both parts</figcaption>
</figure>
</div>

## CAD & print files

- STL: [`balloon-adapter.stl`](https://github.com/boomballoon/boomballoon.github.io/blob/main/hardware/enclosure/stl/balloon-adapter.stl)
- STEP: [`balloon-adapter.stp`](https://github.com/boomballoon/boomballoon.github.io/blob/main/hardware/enclosure/step/balloon-adapter.stp) (tessellated from the mesh)

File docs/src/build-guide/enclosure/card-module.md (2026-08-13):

# Card-Module Housing

*Kartenmodul-Gehäuse* — the tray that carries the optical [card reader](../modules/card-reader.md).
It is an H-shaped structure: two chambers (for the *Lichtmodul* LEDs and the
*Fotomodul* photoresistors) bridged by the drilled slot the card slides through.
It nests inside the [lower housing](lower-housing.md), aligned with the card slot
in the wall.

<div class="gallery" markdown="span">
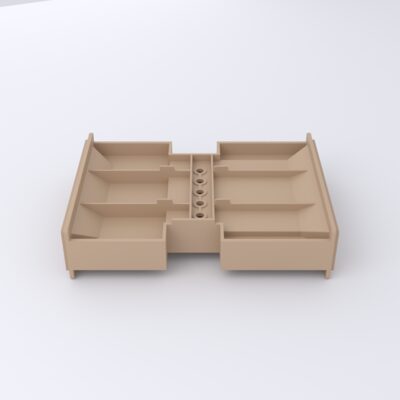
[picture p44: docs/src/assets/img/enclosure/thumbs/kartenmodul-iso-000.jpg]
{ .glightbox data-gallery="kartenmodul" data-title="Card module — iso 0°" }
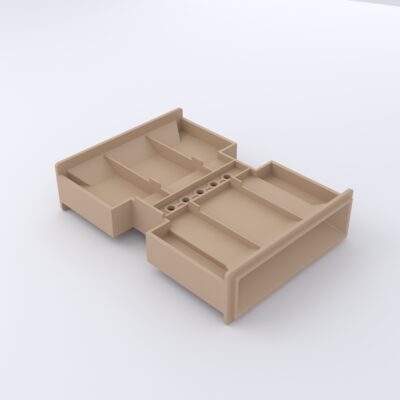
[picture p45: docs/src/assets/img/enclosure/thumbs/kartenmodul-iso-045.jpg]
{ .glightbox data-gallery="kartenmodul" data-title="Card module — iso 45°" }
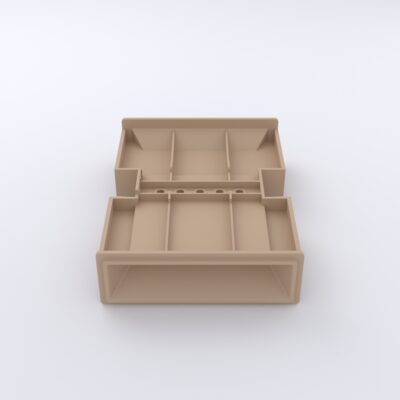
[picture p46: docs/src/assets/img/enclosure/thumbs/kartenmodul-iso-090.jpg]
{ .glightbox data-gallery="kartenmodul" data-title="Card module — iso 90°" }
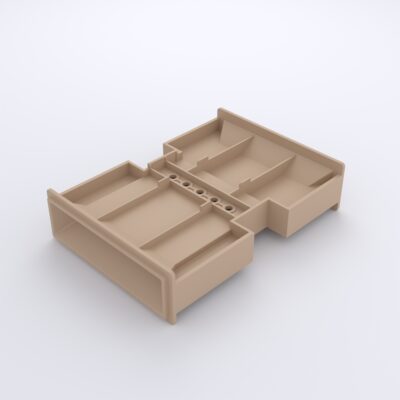
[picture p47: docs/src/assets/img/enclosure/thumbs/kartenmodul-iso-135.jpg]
{ .glightbox data-gallery="kartenmodul" data-title="Card module — iso 135°" }
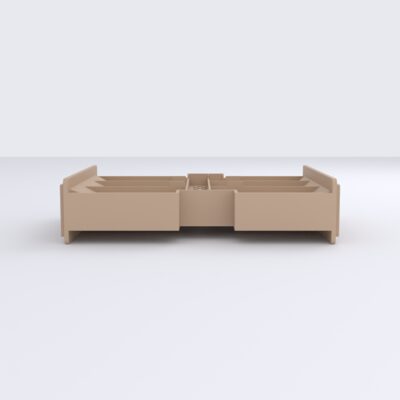
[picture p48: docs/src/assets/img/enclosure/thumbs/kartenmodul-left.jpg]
Card module — profile
{ .glightbox data-gallery="kartenmodul" data-title="Card module — profile" }
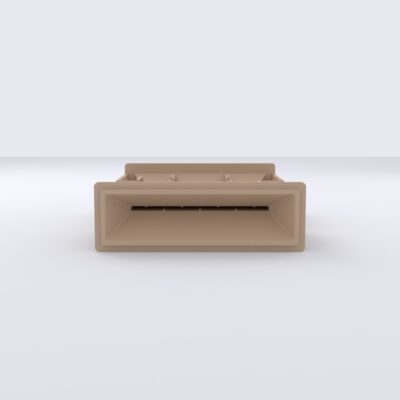
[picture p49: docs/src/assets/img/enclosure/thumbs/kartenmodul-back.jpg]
Card module — end
{ .glightbox data-gallery="kartenmodul" data-title="Card module — end" }
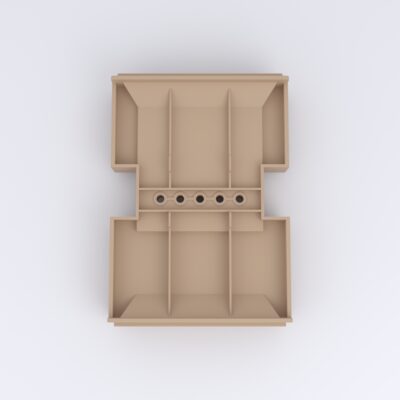
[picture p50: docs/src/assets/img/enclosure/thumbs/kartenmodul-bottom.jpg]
Card module — underside
{ .glightbox data-gallery="kartenmodul" data-title="Card module — underside" }
</div>

**Bounding box:** ≈ 90 × 126 × 30 mm.

## Interior

Sectioning the part reveals the two chambers, the dividing walls, and the drilled
bridge that holds the five photoresistors either side of the card path.

<div class="board-pair" markdown>
<figure markdown="span">
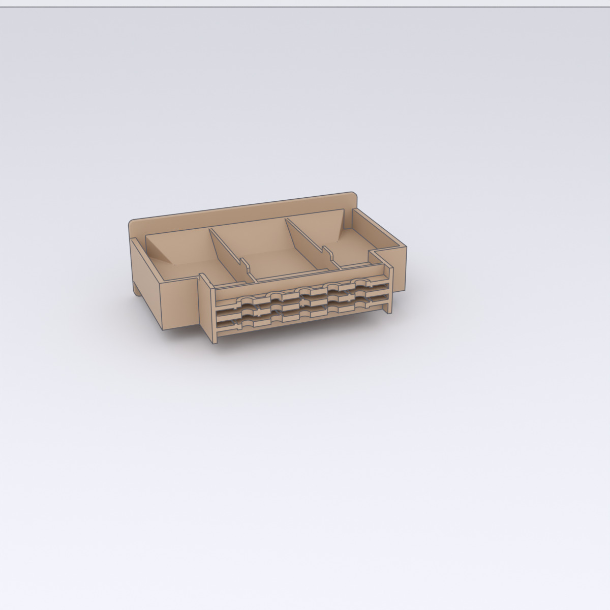
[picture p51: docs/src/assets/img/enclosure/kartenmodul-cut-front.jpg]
Card module — front cut

<figcaption>Front cut — through the chambers</figcaption>
</figure>
<figure markdown="span">
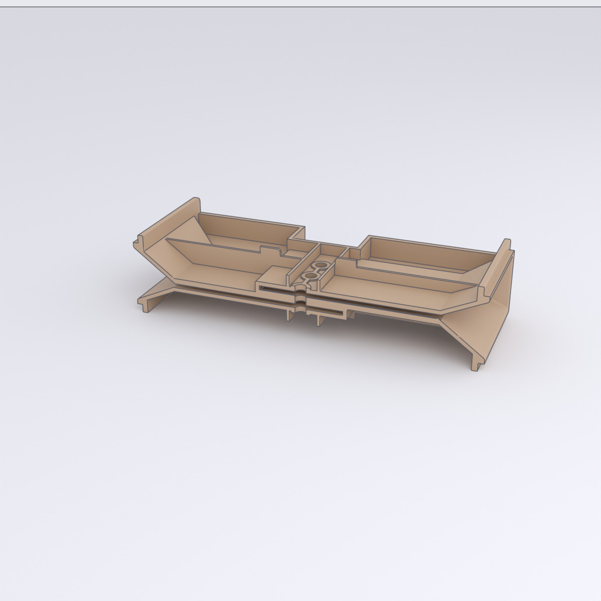
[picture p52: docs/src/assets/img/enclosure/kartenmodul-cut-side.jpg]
Card module — side cut

<figcaption>Side cut — through the drilled photoresistor bridge</figcaption>
</figure>
</div>

## CAD & print files

- STL: [`card-module-housing.stl`](https://github.com/boomballoon/boomballoon.github.io/blob/main/hardware/enclosure/stl/card-module-housing.stl)
- STEP: [`card-module-housing.stp`](https://github.com/boomballoon/boomballoon.github.io/blob/main/hardware/enclosure/step/card-module-housing.stp)

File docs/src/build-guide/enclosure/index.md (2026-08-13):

# Enclosure

The enclosure (*Gehäuse*) is the 3D-printed body that holds everything
together: the balloon and its nozzle, the display window, the card slot, and the
pump/valve mounts.

## Full assembly

The complete device body, all printed parts fitted together.

<div class="gallery" markdown="span">
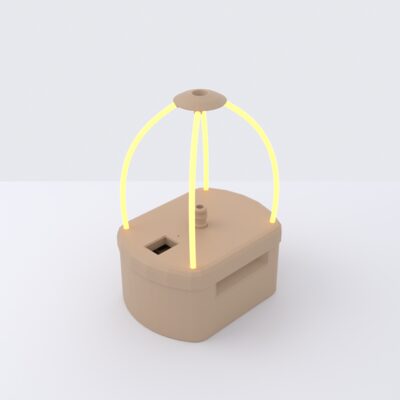
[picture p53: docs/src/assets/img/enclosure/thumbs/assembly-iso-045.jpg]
Assembly — iso
{ .glightbox data-gallery="assembly" data-title="Assembly — iso 45°" }
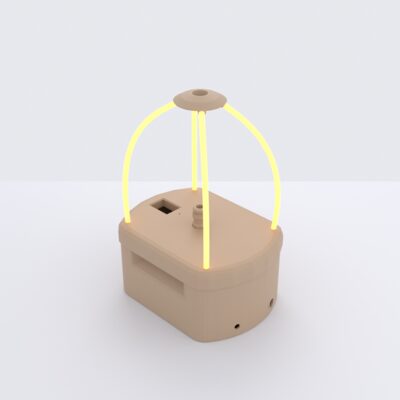
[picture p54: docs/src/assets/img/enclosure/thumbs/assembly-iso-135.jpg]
Assembly — iso
{ .glightbox data-gallery="assembly" data-title="Assembly — iso 135°" }
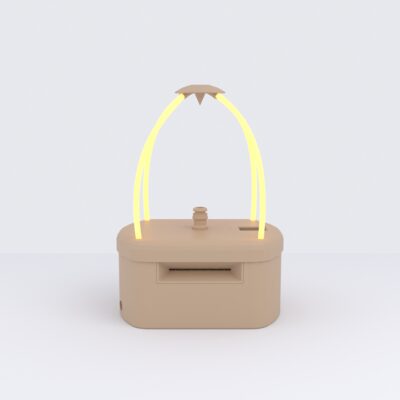
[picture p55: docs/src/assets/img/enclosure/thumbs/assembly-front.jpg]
Assembly — front
{ .glightbox data-gallery="assembly" data-title="Assembly — front" }
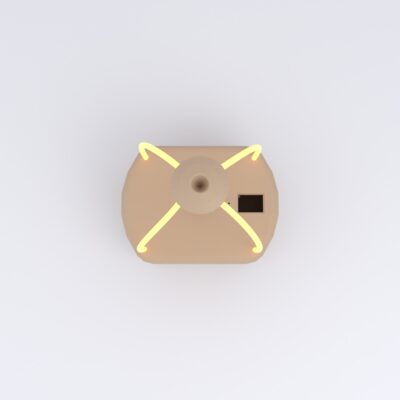
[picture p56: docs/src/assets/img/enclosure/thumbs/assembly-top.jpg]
Assembly — top
{ .glightbox data-gallery="assembly" data-title="Assembly — top" }
</div>

**Overall size:** ≈ 172 × 130 × 237 mm (width × depth × height).

### Interior

Cutaway and partial views of the housing, showing how the card module, balloon
adapter, and hose nozzle sit inside.

<div class="board-pair" markdown>
<figure markdown="span">
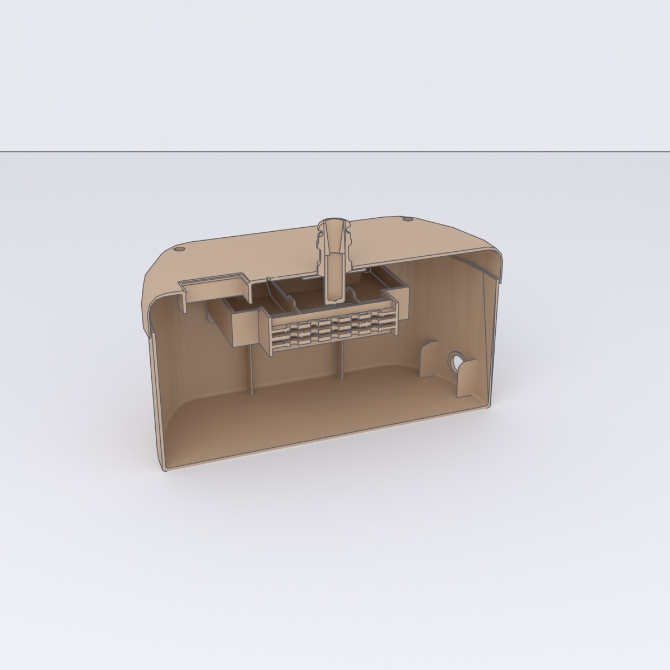
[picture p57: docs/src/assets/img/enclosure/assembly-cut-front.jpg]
Assembly — front cut

<figcaption>Front cut — card module inside the cavity</figcaption>
</figure>
<figure markdown="span">
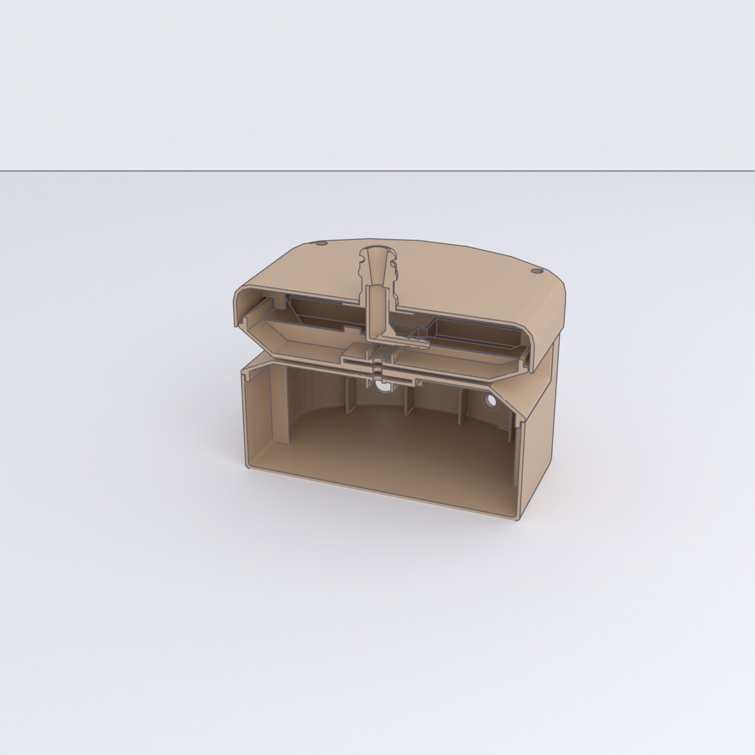
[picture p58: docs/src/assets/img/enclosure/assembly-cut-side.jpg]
Assembly — side cut

<figcaption>Side cut — the adapter and nozzle bore on the centre axis</figcaption>
</figure>
</div>

<div class="board-pair" markdown>
<figure markdown="span">
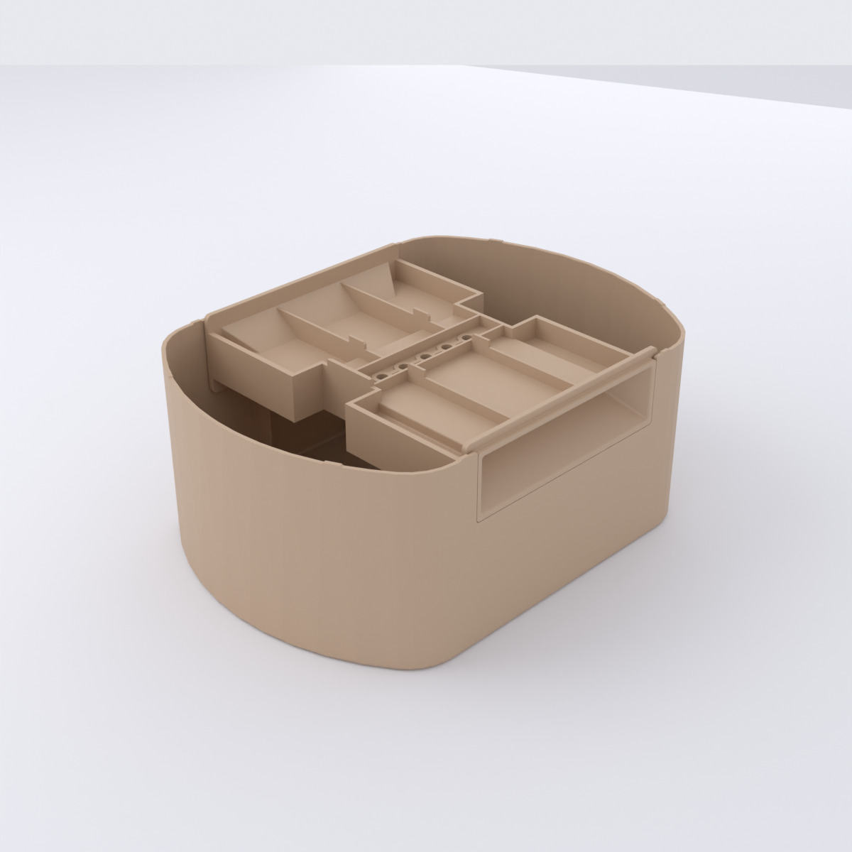
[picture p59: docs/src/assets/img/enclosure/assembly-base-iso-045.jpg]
Lower half from above

<figcaption>Lower half, from above — card module in the base</figcaption>
</figure>
<figure markdown="span">
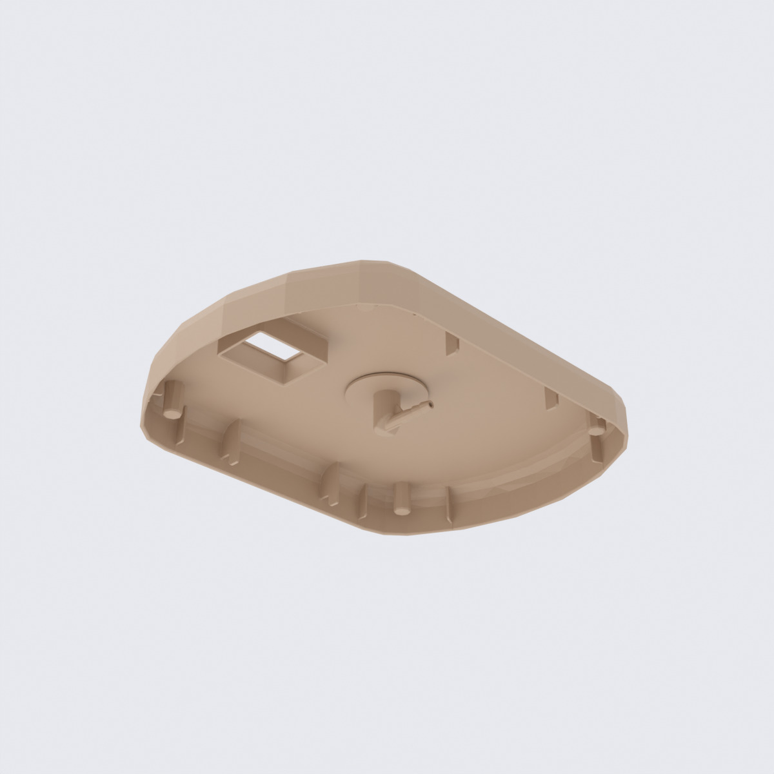
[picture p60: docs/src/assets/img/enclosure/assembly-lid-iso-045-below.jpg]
Upper half from below

<figcaption>Upper half, from below — nozzle and adapter passage</figcaption>
</figure>
</div>

## Parts

The housing splits into several printed parts plus one cut window. Each printed
part has its own page with renders, dimensions, and CAD downloads:

| Part | German name | Role |
|---|---|---|
| [Upper housing](upper-housing.md) | *Gehäuse Oberteil* | upper body shell — carries the display window and nozzle passage |
| [Lower housing](lower-housing.md) | *Gehäuse Unterteil* | lower body shell / base — houses the pump and valve |
| [Roof](roof.md) | *Dach-Spitze* | top cap over the balloon nozzle |
| [Hose nozzle](nozzle.md) | *Schlauch-Stutzen* | balloon nozzle mount (elbow + barbed fitting) |
| [Balloon adapter](balloon-adapter.md) | *Ballon-Aufsatz* | barbed balloon-neck adapter mounted on top of the upper housing |
| [Card-module housing](card-module.md) | *Kartenmodul-Gehäuse* | tray/shroud for the card slot and optical reader |
| Display window | *Scheibe* | polycarbonate pane — **not printed** |

The pump and valve mount inside the lower housing; the display window is a
polycarbonate pane fitted over the 7-segment display.

## CAD files

Neutral-format CAD exports are committed to the repository:

- **Full-assembly STEP:**
  [`full-assembly.stp`](https://github.com/boomballoon/boomballoon.github.io/blob/main/hardware/enclosure/step/full-assembly.stp)
- **STEP** (`.stp`, for CAD/CAM):
  [`hardware/enclosure/step/`](https://github.com/boomballoon/boomballoon.github.io/tree/main/hardware/enclosure/step)
- **STL** (`.stl`, for slicing/printing):
  [`hardware/enclosure/stl/`](https://github.com/boomballoon/boomballoon.github.io/tree/main/hardware/enclosure/stl)

!!! note "The renders are reproducible"
    Every render on these pages is generated from the STL models by
    [`media/enclosure/render.py`](https://github.com/boomballoon/boomballoon.github.io/blob/main/media/enclosure/render.py);
    [`render-all.sh`](https://github.com/boomballoon/boomballoon.github.io/blob/main/media/enclosure/render-all.sh)
    regenerates the exact set. Requires Blender ≥ 4.2.

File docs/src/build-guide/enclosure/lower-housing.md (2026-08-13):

# Lower Housing

*Gehäuse Unterteil* — the lower body shell and base. It is the deep tub that
**houses the pump and valve**, the [control board](../modules/control-board.md),
and the wiring, with a wall cutout for the
[card module](card-module.md) and round holes for the 12 V power connector and
a power switch. The [upper housing](upper-housing.md) caps it.

<div class="gallery" markdown="span">
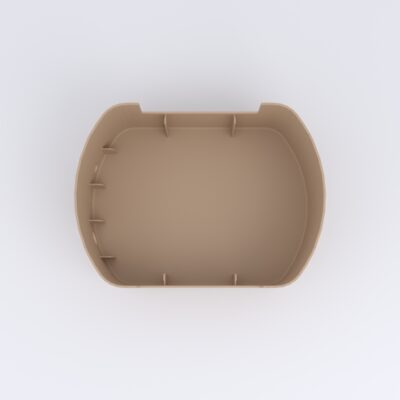
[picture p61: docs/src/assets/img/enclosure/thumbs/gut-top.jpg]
Lower housing — top (into the tub)
{ .glightbox data-gallery="gut" data-title="Lower housing — top (into the tub)" }
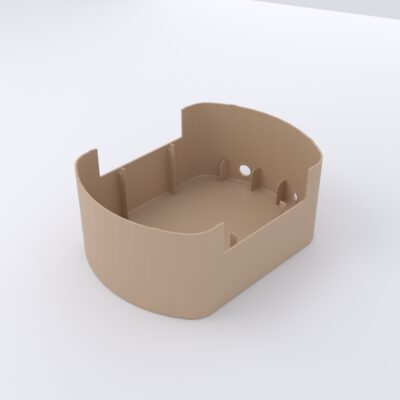
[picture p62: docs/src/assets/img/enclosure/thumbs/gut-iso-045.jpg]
Lower housing — iso
{ .glightbox data-gallery="gut" data-title="Lower housing — iso" }
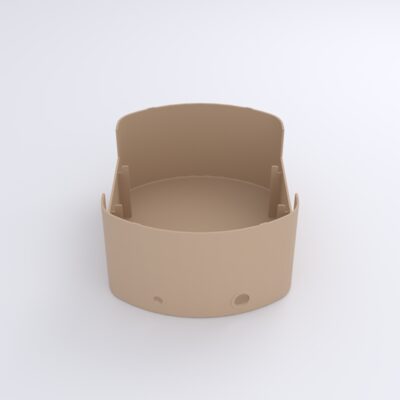
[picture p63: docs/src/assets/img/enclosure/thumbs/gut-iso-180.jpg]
Lower housing — iso (rear)
{ .glightbox data-gallery="gut" data-title="Lower housing — iso (rear)" }
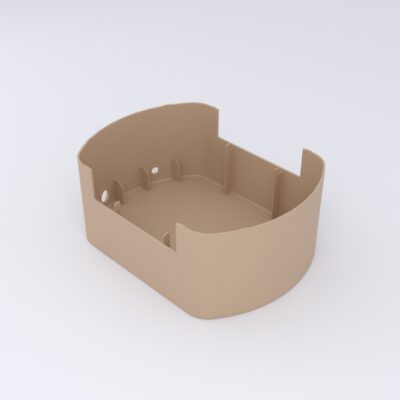
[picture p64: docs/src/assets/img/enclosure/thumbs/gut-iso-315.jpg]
Lower housing — iso (side)
{ .glightbox data-gallery="gut" data-title="Lower housing — iso (side)" }
</div>

**Bounding box:** ≈ 170 × 126 × 71 mm.

## CAD & print files

- STL: [`lower-housing.stl`](https://github.com/boomballoon/boomballoon.github.io/blob/main/hardware/enclosure/stl/lower-housing.stl)
- STEP: [`lower-housing.stp`](https://github.com/boomballoon/boomballoon.github.io/blob/main/hardware/enclosure/step/lower-housing.stp)

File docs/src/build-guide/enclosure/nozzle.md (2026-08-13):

# Hose Nozzle

*Schlauch-Stutzen* — the balloon nozzle mount: a 90° elbow with a wide bore on
one arm (where the [balloon adapter](balloon-adapter.md) sits) and a **barbed
hose fitting** on the other (for the pump/valve tubing). It mounts under the
[upper housing](upper-housing.md).

<div class="gallery" markdown="span">
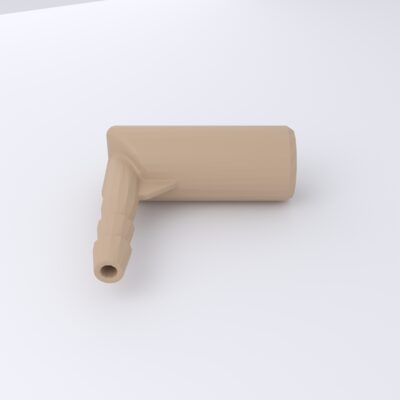
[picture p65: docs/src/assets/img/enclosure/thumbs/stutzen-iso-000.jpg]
Hose nozzle — iso
{ .glightbox data-gallery="stutzen" data-title="Hose nozzle — iso" }
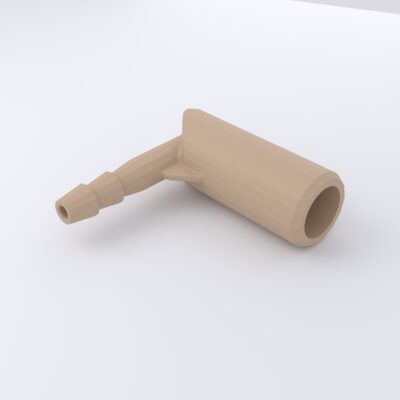
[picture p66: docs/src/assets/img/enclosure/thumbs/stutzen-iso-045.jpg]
Hose nozzle — iso (bore + barb)
{ .glightbox data-gallery="stutzen" data-title="Hose nozzle — iso (bore + barb)" }
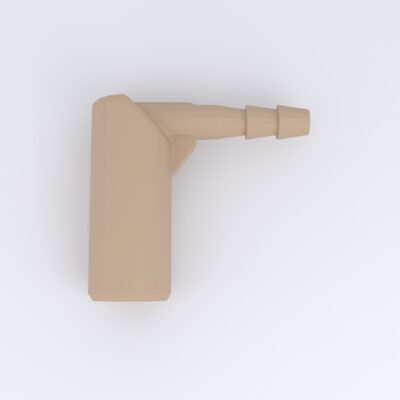
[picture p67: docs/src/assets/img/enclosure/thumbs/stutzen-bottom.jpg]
Hose nozzle — underside
{ .glightbox data-gallery="stutzen" data-title="Hose nozzle — underside" }
</div>

**Bounding box:** ≈ 27 × 24 × 10 mm.

## CAD & print files

- STL: [`hose-nozzle.stl`](https://github.com/boomballoon/boomballoon.github.io/blob/main/hardware/enclosure/stl/hose-nozzle.stl)
- STEP: [`hose-nozzle.stp`](https://github.com/boomballoon/boomballoon.github.io/blob/main/hardware/enclosure/step/hose-nozzle.stp)

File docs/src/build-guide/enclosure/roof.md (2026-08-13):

# Roof

*Dach-Spitze* — a small domed cap that floats above the device on four bent
Knicklichter. A spike points down from
its centre: the balloon inflates up toward it during the game, and touching
the spike is the maximum — inflate past it and the balloon bursts, ending the
game in a loss.

<div class="gallery" markdown="span">
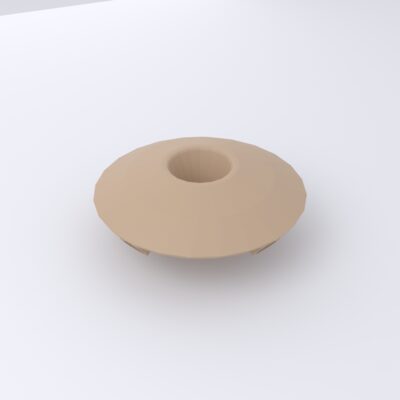
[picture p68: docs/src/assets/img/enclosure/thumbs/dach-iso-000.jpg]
Roof — iso
{ .glightbox data-gallery="dach" data-title="Roof — iso" }
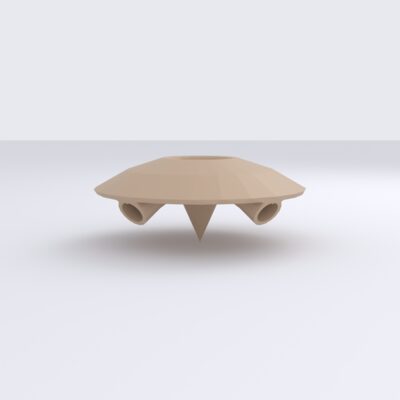
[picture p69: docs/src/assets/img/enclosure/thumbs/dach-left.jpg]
Roof — profile
{ .glightbox data-gallery="dach" data-title="Roof — profile" }
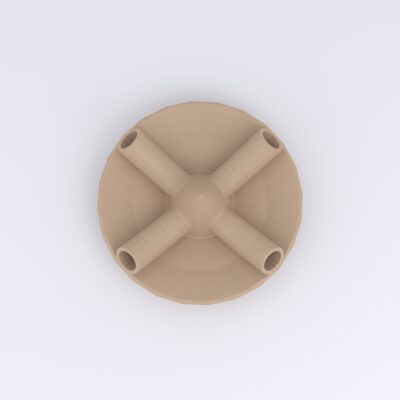
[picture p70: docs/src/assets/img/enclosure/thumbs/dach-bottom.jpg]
Roof — underside (legs)
{ .glightbox data-gallery="dach" data-title="Roof — underside (legs)" }
</div>

**Bounding box:** ≈ 52 × 52 × 21 mm.

## Roof mount

The roof does not sit on the housing — it floats about 140 mm above it,
carried by four bent Knicklichter (flexible glow-stick arm bands). Each stick
leaves a corner hole of the [upper housing](upper-housing.md) near-vertically,
bows outward, and sweeps back in to hook into one of the roof's four leg
bores.

<div class="board-pair" markdown>
<figure markdown="span">
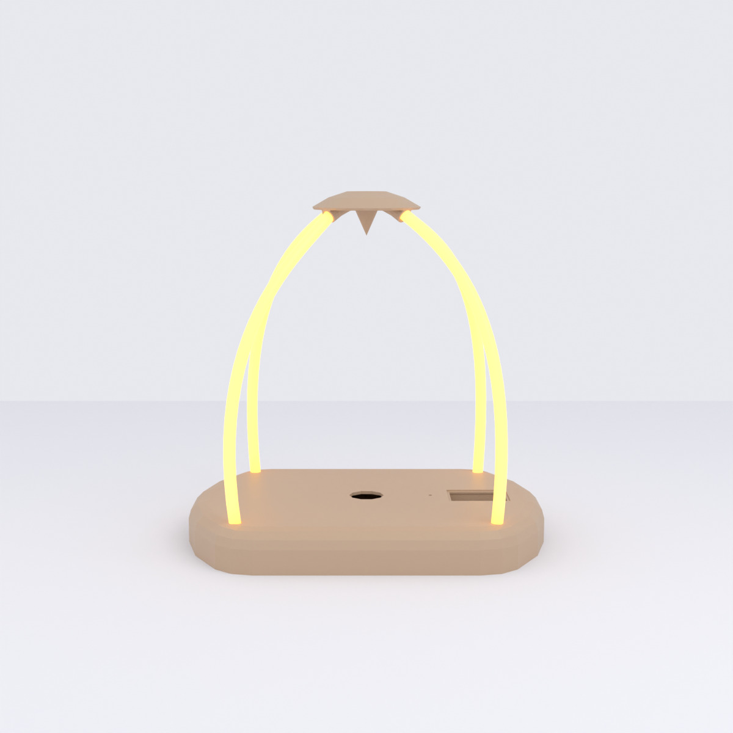
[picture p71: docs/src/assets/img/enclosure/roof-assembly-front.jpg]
Roof mount — front

<figcaption>Front — the roof floating on its four sticks</figcaption>
</figure>
<figure markdown="span">
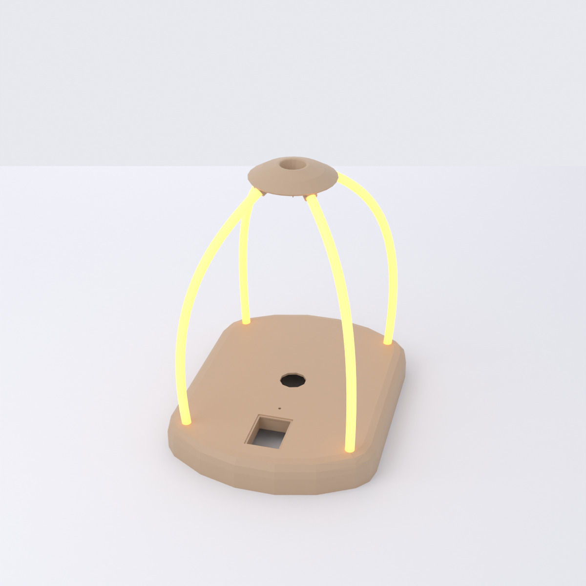
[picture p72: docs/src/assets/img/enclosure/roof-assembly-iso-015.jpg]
Roof mount — iso

<figcaption>Iso — corner hole to leg-bore bend</figcaption>
</figure>
</div>

## CAD & print files

- STL: [`roof.stl`](https://github.com/boomballoon/boomballoon.github.io/blob/main/hardware/enclosure/stl/roof.stl)
- STEP: [`roof.stp`](https://github.com/boomballoon/boomballoon.github.io/blob/main/hardware/enclosure/step/roof.stp)

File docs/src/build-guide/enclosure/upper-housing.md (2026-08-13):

# Upper Housing

*Gehäuse Oberteil* — the upper body shell. Its outer face carries the **display
window** cutout and the passage for the [balloon adapter](balloon-adapter.md)
and [hose nozzle](nozzle.md); it mates onto the [lower housing](lower-housing.md).
The four holes at the corners take bendable Knicklichter — flexible glow-stick
arm bands — that plug into the [roof](roof.md)'s hollow legs, holding it in
place above the housing.

<div class="gallery" markdown="span">
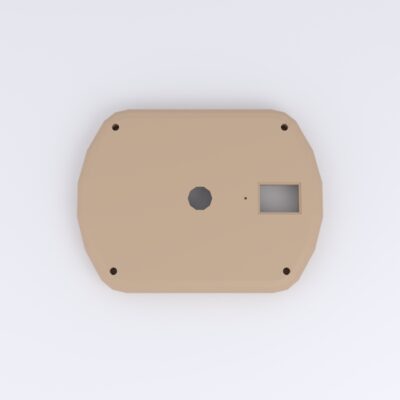
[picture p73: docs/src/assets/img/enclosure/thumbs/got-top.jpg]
Upper housing — top (outer face)
{ .glightbox data-gallery="got" data-title="Upper housing — top (outer face)" }
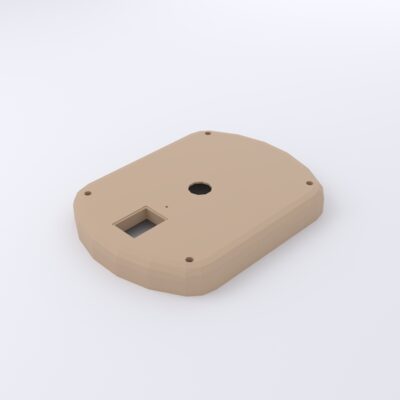
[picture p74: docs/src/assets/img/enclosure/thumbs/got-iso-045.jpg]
Upper housing — iso
{ .glightbox data-gallery="got" data-title="Upper housing — iso" }
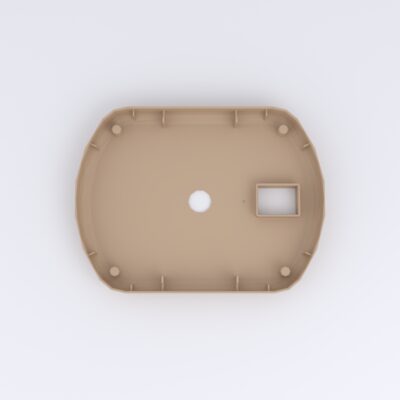
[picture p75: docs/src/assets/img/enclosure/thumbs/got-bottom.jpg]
Upper housing — underside (interior)
{ .glightbox data-gallery="got" data-title="Upper housing — underside (interior)" }
</div>

**Bounding box:** ≈ 172 × 130 × 20 mm.

## CAD & print files

- STL: [`upper-housing.stl`](https://github.com/boomballoon/boomballoon.github.io/blob/main/hardware/enclosure/stl/upper-housing.stl)
- STEP: [`upper-housing.stp`](https://github.com/boomballoon/boomballoon.github.io/blob/main/hardware/enclosure/step/upper-housing.stp)

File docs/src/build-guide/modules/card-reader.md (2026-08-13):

# Card Reader

The card reader (*Kartenmodul*, card module) is how the device knows which card
a player has inserted. It is an **optical** reader: it shines light through the
card and measures where the light gets through.

It is built from two stacked PCBs:

- the **Lichtmodul** (light module) — the illuminator, and
- the **Fotomodul** (photo module) — the sensor.

A card slides into the gap between them. Each card carries a pattern of clear
and opaque spots; the sensors below read that pattern as a 5-bit value. The
encoding itself is documented separately in the
[Optical Code System](../../reference/optical-codes.md) reference.

## Lichtmodul (light module)

The *Lichtmodul* is the light source. It carries **5× 3 mm LEDs**, each with its
own **330 Ω** series resistor to limit current. The five LEDs sit directly above
the five sensors on the *Fotomodul*, so each sensor is lit from above through
the card.

<div class="board-pair" markdown>
<figure markdown="span">
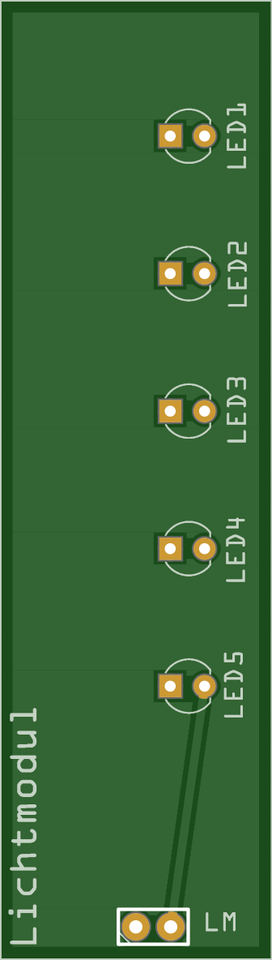
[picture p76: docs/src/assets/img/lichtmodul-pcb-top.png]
Lichtmodul PCB, top side

<figcaption>Lichtmodul PCB — top</figcaption>
</figure>
<figure markdown="span">
Lichtmodul PCB, bottom side
<figcaption>Lichtmodul PCB — bottom</figcaption>
</figure>
</div>

### Board markings

| Marking | What it is |
|---|---|
| `LED1`–`LED5` | The five 3 mm LEDs. |
| `R1`–`R5` | The 330 Ω series resistor belonging to the LED of the same number, mounted as SMD parts on the bottom side. |
| `LM` | The 2-pin connector (*Lichtmodul*) carrying power for the LEDs. It plugs into the matching `LM` header on the *Fotomodul* below. |
| `1` | Pin-1 marker, printed next to `LM`. |

### Parts & datasheets

The components populated on the *Lichtmodul*, with the datasheet for each part
archived in the repo where available.

| Component | Qty | Part / supplier | Datasheet |
|---|---|---|---|
| 3 mm white LED | 5 | Reichelt LED EL 3-11250KW (Bürklin 67 S 4470) | [PDF](https://github.com/boomballoon/boomballoon.github.io/blob/main/hardware/datasheets/204-15UTC-S400-X9-L_V2.pdf) |
| 330 Ω resistor (SMD 1206) | 5 | Reichelt SMD 1206, LED series resistor | [PDF](https://github.com/boomballoon/boomballoon.github.io/blob/main/hardware/datasheets/SMD_1206.pdf) |

### Gallery

Photos of the board, before and after assembly. Click any of them for a larger view.

<div class="gallery" markdown="span">
Lichtmodul before assembly: the bare PCB (LED footprints on top, SMD resistor pads on the bottom), five 3 mm LEDs, the SMD 330 Ω resistors, and the LM connector.{ .glightbox data-gallery="lichtmodul" data-title="Lichtmodul — parts before assembly" }
Assembled Lichtmodul boards: the five 3 mm LEDs (LED1–LED5) and the LM power header.{ .glightbox data-gallery="lichtmodul" data-title="Lichtmodul — assembled, LEDs populated" }
</div>

Fritzing source:
[`Kartenleser_Lichtmodul.fzz`](https://github.com/boomballoon/boomballoon.github.io/blob/main/hardware/card-reader/Kartenleser_Lichtmodul.fzz).

## Fotomodul (photo module)

The *Fotomodul* is the sensor board. It carries **5× photoresistors**
(light-dependent resistors, Reichelt A 905014), each forming a
**voltage divider** with a **330 Ω** resistor. Each divider's midpoint feeds one
of the Arduino's analog inputs, `A0`–`A4`. A lit sensor (light passing through a
clear spot on the card) and an unlit sensor (light blocked by an opaque spot)
produce clearly different analog voltages, which the firmware thresholds into
the 5 bits of the card code.

<div class="board-pair" markdown>
<figure markdown="span">
Fotomodul PCB, top side
<figcaption>Fotomodul PCB — top</figcaption>
</figure>
<figure markdown="span">
Fotomodul PCB, bottom side
<figcaption>Fotomodul PCB — bottom</figcaption>
</figure>
</div>

### Board markings

| Marking | What it is |
|---|---|
| `F1`–`F5` | The five photoresistors. Each one lines up under an LED on the *Lichtmodul*. |
| `R1`–`R5` | The 330 Ω divider resistor belonging to the sensor of the same number, mounted as SMD parts on the bottom side. |
| `LM` | The 2-pin header that feeds the *Lichtmodul* stacked above. |
| `FM` | The 7-pin header to the [control board](control-board.md) — 3.3 V, GND, and `A0`–`A4`. Pinout in the [table below](#fotomodul-connector-7-pin). |
| `Connector` | A 6-pin **pass-through for the display cable**, electrically no part of the card reader. The control board sits at the bottom of the case and the *Fotomodul* in the middle, so relaying the display cable through here keeps the display in the lid easy to unplug. |
| `1` | Pin-1 marker, printed next to `LM` and `FM`. |

### Parts & datasheets

The components populated on the *Fotomodul*, with the datasheet for each part
archived in the repo where available. Its 330 Ω divider resistors are the same
SMD 1206 part as on the *Lichtmodul* — see the
[note on the BOM page](../../reference/bill-of-materials.md).

| Component | Qty | Part / supplier | Datasheet |
|---|---|---|---|
| Photoresistor (LDR) | 5 | Reichelt A 905014 (Conrad 145475-62) | [PDF](https://github.com/boomballoon/boomballoon.github.io/blob/main/hardware/datasheets/A90xxxx%23PE.pdf) |
| 330 Ω resistor (SMD 1206) | 5 | Reichelt SMD 1206, divider resistor | [PDF](https://github.com/boomballoon/boomballoon.github.io/blob/main/hardware/datasheets/SMD_1206.pdf) |

### Gallery

Photos of the board, before and after assembly. Click any of them for a larger view.

<div class="gallery" markdown="span">
Fotomodul before assembly: the bare PCB, five photoresistors, the SMD divider resistors, and the LM/FM headers.{ .glightbox data-gallery="fotomodul" data-title="Fotomodul — parts before assembly" }
Assembled Fotomodul boards: the five photoresistors (F1–F5), the FM header, and the display pass-through connector.{ .glightbox data-gallery="fotomodul" data-title="Fotomodul — assembled, photoresistors populated" }
</div>

Fritzing source:
[`Kartenleser_Fotomodul.fzz`](https://github.com/boomballoon/boomballoon.github.io/blob/main/hardware/card-reader/Kartenleser_Fotomodul.fzz).

### Fotomodul connector (7-pin)

The *Fotomodul* connects to the [control board](control-board.md) through a
7-pin header. Note the module runs at **3.3 V**, not 5 V, for a stable analog
reference:

| Pin | Signal | Notes |
|---|---|---|
| 1 | Vcc | **3.3 V** |
| 2 | GND | |
| 3 | A0 | card bit 0 |
| 4 | A1 | card bit 1 |
| 5 | A2 | card bit 2 |
| 6 | A3 | card bit 3 |
| 7 | A4 | card bit 4 |

The `A0`–`A4` lines land on the Arduino's analog inputs. For the complete signal
map across all modules, see the [wiring](../wiring.md).

## Calibration

Because photocell behaviour depends on the exact LEDs, ambient light, and card
material, the firmware ships with a bring-up harness that prints raw analog
values so you can pick thresholds. See
[`DETECTOR_CALIBRATION`](../firmware.md#build-switches) on the
firmware page.

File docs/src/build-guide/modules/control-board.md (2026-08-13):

# Control Board

The control board (*Steuermodul*, control module) is the **hub** of the device.
The Arduino Nano sits on it, the 12 V power comes in here, and the other two
modules — the [card reader](card-reader.md) and the [display](display.md) — plug
into it. It also carries the power electronics that switch the two 12 V loads:
the inflate pump and the deflate valve.

<div class="board-pair" markdown>
<figure markdown="span">
Steuermodul PCB, top side
<figcaption>Steuermodul PCB — top (Arduino and connectors)</figcaption>
</figure>
<figure markdown="span">
Steuermodul PCB, bottom side
<figcaption>Steuermodul PCB — bottom</figcaption>
</figure>
</div>

### Board markings

| Marking | What it is |
|---|---|
| `Motor` | The 3-pin footprint for the **pump** channel's TIP120 (*Motor* = the inflate pump). |
| `Ablassmotor` | The same for the **valve** channel (*Ablassmotor* = release motor, the deflate solenoid). |
| `D1`, `D2` | The 1N4004 flyback diodes, one per channel, cathode toward +12 V. |
| `R1`, `R2` | The 2.2 kΩ base resistors, one per channel, between the MCU pin and the transistor base. |
| `MA`, `MM` | The **pump** output terminals, 12 V switched by `D6`. |
| `VA`, `VM` | The **valve** output terminals, 12 V switched by `D7`. |
| `Vcc 12V` | The 2-pin 12 V supply input. |
| `Fotomodul` | The 7-pin header to the [card reader](card-reader.md). |
| `Displaymodul` | The 6-pin header to the [display](display.md). |
| `1` | Pin-1 marker, printed next to each keyed header. |

The single unlabelled pads in rows beside the Arduino footprint are direct
break-outs of its pins, there so a signal can be tapped or jumpered by hand.

### Fitting the Nano in the Micro footprint

The footprint has **17 holes per row** — the Micro's pin count. The Nano has
15 per row, but the two layouts are compatible by design: the Micro's pinout
is the Nano's plus two extra pins per row at the far-from-USB end (its SPI
pins `D14`–`D17`), and its `NC` positions sit where the Nano has `A6`/`A7`.
Compare the two boards (both shown from the top, USB up):

<div class="board-pair" markdown>
<figure markdown="span">
Arduino Micro pinout
<figcaption>Arduino Micro — its extra SPI pins (D14–D17) sit at the far-from-USB end; the two NC holes fall where the Nano instead has A6/A7</figcaption>
</figure>
<figure markdown="span">
Arduino Nano pinout
<figcaption>Arduino Nano — all 30 pins land in the footprint, aligned to the USB end (A6/A7 fall in the Micro's NC holes)</figcaption>
</figure>
</div>

To place the Nano on the board:

- **USB connector toward the `Displaymodul`/`Fotomodul` headers** — the same
  direction the Micro's USB would face. The `D12` and `D13` holes are in that
  corner of the footprint.
- **Align flush with that USB end.** Every Nano pin then sits in the hole
  carrying its own name: `TX1`→`TX1` … `D12`→`D12` on one row, `VIN`→`VIN` …
  `D13`→`D13` on the other.

### Parts & datasheets

The components populated on the board, with the datasheet for each part archived
in the repo where available.

| Component | Qty | Part / supplier | Datasheet |
|---|---|---|---|
| Arduino Nano (ATmega328P) | 1 | Keywish Nano (footprint drawn for an Arduino Micro) | — |
| TIP120 Darlington transistor | 2 | STM (Reichelt) | [PDF](https://github.com/boomballoon/boomballoon.github.io/blob/main/hardware/datasheets/TIP120_TIP121_TIP122_TIP125_TIP126_TIP127%23STM.pdf) |
| 1N4004 flyback diode | 2 | Fairchild | [PDF](https://github.com/boomballoon/boomballoon.github.io/blob/main/hardware/datasheets/1N400x_FAI.pdf) |
| 2.2 kΩ resistor (metal film) | 2 | Reichelt METALL 2,20K, transistor base | [PDF](https://github.com/boomballoon/boomballoon.github.io/blob/main/hardware/datasheets/METALL%23YAG.pdf) |

The board is also the wiring hub for the power-entry parts and the two 12 V
loads it switches. These are **not** on the PCB — they mount in the enclosure
and land on the screw terminals — but are listed here since they are electrically
part of this module:

| Component | Qty | Part / supplier | Datasheet |
|---|---|---|---|
| DC socket (switched) | 1 | BKL 072342 | [PDF](https://github.com/boomballoon/boomballoon.github.io/blob/main/hardware/datasheets/072342.pdf) |
| Toggle switch (on/off) | 1 | MS-165 series | [PDF](https://github.com/boomballoon/boomballoon.github.io/blob/main/hardware/datasheets/MS-165_169.pdf) |
| Membrane pump (inflate) | 1 | AIRPO D2028B (12 V) | [PDF](https://github.com/boomballoon/boomballoon.github.io/blob/main/hardware/datasheets/AIRPO%20D2028B.pdf) |
| Solenoid valve (deflate) | 1 | CEME 5000EN1,5P | [PDF](https://github.com/boomballoon/boomballoon.github.io/blob/main/hardware/datasheets/Druckluft-Magnetventil%20CEME%205000EN1%2C5P.pdf) |

### Gallery

Photos of the board, before and after assembly. Click any of them for a larger view.

<div class="gallery" markdown="span">
Control-board parts before assembly: the bare Steuermodul PCB, the Arduino Nano, two TIP120 transistors, the flyback diodes and base resistors, the pin headers, and the wiring.{ .glightbox data-gallery="steuermodul" data-title="Steuermodul — parts before assembly" }
The assembled control board: the Arduino Nano in its footprint, the two TIP120 channels, and the Motor/valve, 12 V, Fotomodul and Displaymodul headers.{ .glightbox data-gallery="steuermodul" data-title="Steuermodul — assembled, with the Nano fitted" }
</div>

## 12V Power switching

The Arduino cannot drive the 12 V pump or valve directly, so each load has a
**TIP120 Darlington transistor** acting as a low-side switch. There are two
identical channels:

- **Pump channel** — output terminals **MA/MM** (*Motor*), drives the AIRPO
  D2028B membrane pump (inflate). Controlled by MCU pin **D6**.
- **Valve channel** — output terminals **VA/VM** (*Ventil*, valve), drives the
  CEME 5000EN1,5P solenoid valve (deflate). Controlled by MCU pin **D7**.

Each channel is the textbook TIP120 low-side driver: the MCU pin drives the
base through a 2.2 kΩ resistor, the load sits between +12 V and the
collector, the emitter goes to ground, and a flyback diode bridges the load
(cathode to +12 V) to clamp the inductive kick when the transistor switches
off. One channel looks like this (`Dx` is `D6` for the pump, `D7` for the
valve):

<div class="wiring-diagram" markdown>
<figure markdown="span">
TIP120 low-side switch schematic: Arduino pin through a 2.2 kΩ base resistor into the TIP120 base, the load between +12 V and the collector, a 1N4004 flyback diode across the load with its cathode toward +12 V, and the emitter to ground.
<figcaption>One channel of the low-side switch — the pump and valve channels are identical, on D6/MA·MM and D7/VA·VM respectively</figcaption>
</figure>
</div>

The design basis is the **TIP120 tutorial**, archived here as
[`Motorsteuerung.pdf`](https://github.com/boomballoon/boomballoon.github.io/blob/main/hardware/control/Motorsteuerung.pdf).

## Connectors

Everything meets on this board:

| Connector | To module | Pins |
|---|---|---|
| Fotomodul header | [Card reader](card-reader.md) | 7-pin (3.3 V, `A0`–`A4`) |
| Displaymodul header | [Display](display.md) | 6-pin (5 V, `DS`/`STCP`/`SHCP`/buzzer) |
| Power input | 12 V / 3 A supply | via switched DC socket |
| Pump output (MA/MM) | AIRPO pump | 12 V, switched by D6 |
| Valve output (VA/VM) | CEME valve | 12 V, switched by D7 |

Fritzing source:
[`Steuermodul.fzz`](https://github.com/boomballoon/boomballoon.github.io/blob/main/hardware/control/Steuermodul.fzz).

For the complete, authoritative signal map — including which analog and digital
pins each connector carries — see the [wiring](../wiring.md).

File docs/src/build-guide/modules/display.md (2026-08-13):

# Display

The display (*Displaymodul*) is the device's only visual output: a single
**20 mm 7-segment digit** that shows the current player number, countdowns, and
game state. It also carries the **piezo buzzer** for game sounds. Both are
driven from just four Arduino pins, because the segments go through a shift
register.

## Circuit

A single **74HC595** shift register (SMD) drives the display. The Arduino clocks
8 bits into the register serially; the register's eight outputs drive the seven
segments plus the decimal point, each through its own **330 Ω** current-limiting
resistor (**8× 330 Ω** total). This trades three fast MCU pins for eight segment
lines.

The 7-segment digit is **common cathode** (part SC08-11). The buzzer (EKULIT
AL-60P12) is driven directly from a dedicated MCU pin.

<div class="board-pair" markdown>
<figure markdown="span">
Displaymodul PCB, top side
<figcaption>Displaymodul PCB — top</figcaption>
</figure>
<figure markdown="span">
Displaymodul PCB, bottom side
<figcaption>Displaymodul PCB — bottom</figcaption>
</figure>
</div>

### Board markings

| Marking | What it is |
|---|---|
| `Summer` | The piezo buzzer (*Summer* is German for buzzer). The `+` marks its positive pin. |
| `U1` | The 74HC595 shift register, an SOIC-16 SMD part on the bottom side. The dot and the notch in its outline mark pin 1. |
| `R1`–`R8` | The eight 330 Ω series resistors, one per shift-register output: seven segments plus the decimal point. SMD, bottom side. |
| `Display` | The 6-pin connector to the [control board](control-board.md). Pinout in the [table below](#connector-6-pin). |

### Parts & datasheets

The components populated on the board, with the datasheet for each part archived
in the repo where available. The eight segment resistors are the same 330 Ω SMD
1206 part used elsewhere — see the [note on the BOM page](../../reference/bill-of-materials.md).

| Component | Qty | Part / supplier | Datasheet |
|---|---|---|---|
| 7-segment 20 mm digit (common cathode) | 1 | SC08-11 | [PDF](https://github.com/boomballoon/boomballoon.github.io/blob/main/hardware/datasheets/SC08-11SRWA%28V6%29.pdf) |
| 74HC595 shift register (SOIC-16, SMD) | 1 | SMD HC 595 | [PDF](https://github.com/boomballoon/boomballoon.github.io/blob/main/hardware/datasheets/smd_hc_595.pdf) |
| 330 Ω resistor (SMD 1206) | 8 | Reichelt SMD 1206, segment resistors | [PDF](https://github.com/boomballoon/boomballoon.github.io/blob/main/hardware/datasheets/SMD_1206.pdf) |
| Piezo buzzer | 1 | EKULIT AL-60P12 | [PDF](https://github.com/boomballoon/boomballoon.github.io/blob/main/hardware/datasheets/155120AL-60P12.pdf) |

### Gallery

Photos of the board, before and after assembly. Click any of them for a larger view.

<div class="gallery" markdown="span">
The bare Displaymodul PCBs: the top with the buzzer and 7-segment digit footprints, the bottom with the 74HC595 and the eight segment-resistor pads.{ .glightbox data-gallery="displaymodul" data-title="Displaymodul — bare PCBs, both sides" }
Assembled Displaymodul, top side: the 7-segment digit and the piezo buzzer.{ .glightbox data-gallery="displaymodul" data-title="Displaymodul — top side, assembled" }
Assembled Displaymodul, bottom side: the 74HC595 and the eight 330 Ω resistors.{ .glightbox data-gallery="displaymodul" data-title="Displaymodul — bottom side, assembled" }
Assembled Displaymodul edge on, with the 6-pin header and the display's part label.{ .glightbox data-gallery="displaymodul" data-title="Displaymodul — edge on, showing the header and the display's part label" }
Three assembled Displaymodul boards: the 7-segment digit, the piezo buzzer, and the 6-pin header.{ .glightbox data-gallery="displaymodul" data-title="Displaymodul — assembled boards" }
</div>

Fritzing source:
[`Displaymodul.fzz`](https://github.com/boomballoon/boomballoon.github.io/blob/main/hardware/display/Displaymodul.fzz).

## Connector (6-pin)

The module connects to the [control board](control-board.md) through a 6-pin
header. The three shift-register control lines and the buzzer map to Arduino
digital pins as shown. The module runs at **5 V**:

| Pin | Signal | 74HC595 role | MCU pin |
|---|---|---|---|
| 1 | Vcc | +5 V | — |
| 2 | GND | | — |
| 3 | DS | serial **data** in | **D8** |
| 4 | STCP | storage-register clock (**latch**) | **D9** |
| 5 | SHCP | shift-register **clock** | **D10** |
| 6 | Buzzer | piezo buzzer drive | **D11** |

To update the digit, the firmware shifts 8 bits out on `DS`/`SHCP` (`D8`/`D10`),
then pulses `STCP` (`D9`) to latch them to the outputs. For the complete signal
map across all modules, see the [wiring](../wiring.md).

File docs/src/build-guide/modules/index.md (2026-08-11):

# Modules

This chapter describes the electronics that make the game work. They are
split into three cooperating modules, each holding a distinct part of the
circuit on its own dedicated PCB. This keeps soldering and wiring simple —
each small board can be populated and tested on its own before everything is
connected. Each module has its own page describing it in detail.

The three electronic modules — card reader, control board, and display{ .glightbox data-title="The three electronic modules — card reader, control board, and display" }

- [Card reader](card-reader.md) — *Kartenmodul* (card module)
- [Display](display.md) — *Displaymodul*
- [Control board](control-board.md) — *Steuermodul* (control module)

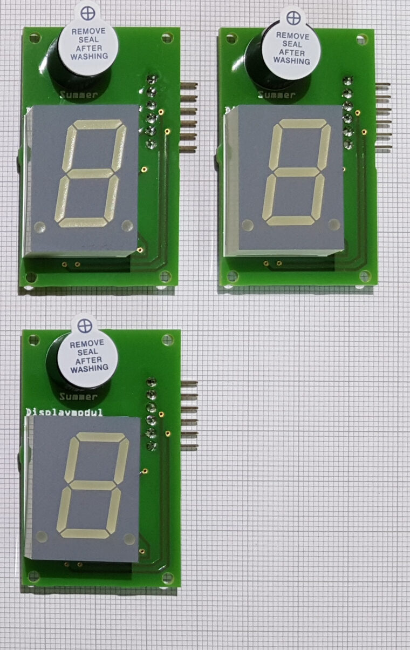
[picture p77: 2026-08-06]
docs/src/assets/img/gallery/displaymodul-assembled.jpg

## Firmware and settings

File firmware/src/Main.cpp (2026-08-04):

#include <Arduino.h>

#include <Constants.h>

#include <Game.h>
#include <PlayerChooser.h>
#include <Devices/CodeDetector.h>
#include <Devices/OutputDevice.h>
#include <Devices/PiezoBuzzer.h>
#include <Devices/SevenSegmentDisplay.h>
#include <Tasks/TaskScheduler.h>
#include <Helper/Log.h>

#ifdef MOCK_CODE_DETECTOR
#include <Mock/CodeDetectorMock.h>
#endif
#ifdef MOCK_OUTPUT_DEVICE
#include <Mock/OutputDeviceMock.h>
#endif

//-----------------------------------------------------------------------------

Game game;

#ifdef DETECTOR_CALIBRATION
bool paused = false;
bool displayChangesOnly = false;
#endif

//-----------------------------------------------------------------------------

/**
 * @brief setup setup everything needed for the program to run.
 */
void setup() {

    SevenSegmentDisplay::instance = new SevenSegmentDisplay(PIN_9, PIN_10, PIN_8);
    SevenSegmentDisplay::instance->setup();
    SevenSegmentDisplay::instance->setCharacter(CHAR_MINUS);

    // when driving the game over serial (mock builds), wait so the serial
    // connection is established and the opening prompt isn't missed
    #if defined(MOCK_CODE_DETECTOR) || defined(MOCK_OUTPUT_DEVICE)
    delay(2500);
    #endif
    SevenSegmentDisplay::instance->setCharacter(CHAR_DOT);

    Log::setup();
    randomSeed(analogRead(PIN_A5)); //PIN 5 needs to be unconnected

    PlayerChooser::instance = new PlayerChooser(CODE_15, CODE_17, CODE_19, CODE_21, CODE_23);

    TaskScheduler::instance = new TaskScheduler();

    #ifdef MOCK_OUTPUT_DEVICE
    OutputDevice::instance = new OutputDeviceMock(PIN_6, PIN_7);
    #else
    OutputDevice::instance = new OutputDevice(PIN_6, PIN_7);
    #endif

    #ifdef MOCK_CODE_DETECTOR
    CodeDetector::instance = new CodeDetectorMock(PIN_A0, PIN_A1, PIN_A2, PIN_A3, PIN_A4);
    #else
    CodeDetector::instance = new CodeDetector(PIN_A0, PIN_A1, PIN_A2, PIN_A3, PIN_A4);
    #endif

    PiezoBuzzer::instance  = new PiezoBuzzer(PIN_11);


    OutputDevice::instance->setup();
    CodeDetector::instance->setup();
    PiezoBuzzer::instance->setup();

    #ifndef DETECTOR_CALIBRATION
    printf("=================================\n");
    printf("=== Select number of players  ===\n");
    printf("=================================\n");
    #else
    printf("=====================================\n");
    printf("=== <SPACE> = Pause               ===\n");
    printf("===   <TAB> = Toggle Display Mode ===\n");
    printf("=====================================\n");
    #endif

    #ifdef AUTOSTART_GAME
    game.start(2, false);
    #endif
}

//-----------------------------------------------------------------------------

#ifndef DETECTOR_CALIBRATION
/**
 * @brief loop main loop for the program.
 */
void loop() {

    if (!game.isStarted()) {
        if (PlayerChooser::instance->detectNumPlayers() && CodeDetector::instance->getActiveCode() == CODE_ALL) {
            game.start(PlayerChooser::instance->getNumPlayers());
        }
    } else {
        //game running
        game.loop();
    }
}

//-----------------------------------------------------------------------------

#else // DETECTOR_CALIBRATION
void loop() {

    if (!paused) {
        bool codeChanged = CodeDetector::instance->codeChanged();
        CodeDetector::instance->printRawValues(codeChanged, displayChangesOnly);
    }

    int sleep = 0;

    while (sleep++ < 500) {
        if (Serial.available() > 0) {
            char receivedChar = Serial.read();

            if (receivedChar == CHAR_SPACE) {
                paused = !paused;
                if (paused) {
                    printf("<PAUSED>\n");
                }
            } else if (receivedChar == CHAR_TAB) {
                displayChangesOnly = !displayChangesOnly;
            }
        }
        delay(1);
    }
}
#endif

//-----------------------------------------------------------------------------

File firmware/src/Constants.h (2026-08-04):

#ifndef CONSTANTS
#define CONSTANTS

#include <stdio.h>
#include <avr/pgmspace.h>

// Keep printf format strings in flash instead of SRAM. On the ATmega328P a
// plain printf("...") copies its literal into RAM at boot; PSTR + printf_P read
// it straight from flash, which is what lets logging stay always-on cheaply.
// (Format strings must be literals — which every call site here is.)
#define printf(fmt, ...) printf_P(PSTR(fmt), ##__VA_ARGS__)

//#define AUTOSTART_GAME

// Wire in the serial mocks from src/Mock/ instead of the real devices, so the
// game can be driven and observed over serial with no hardware attached. Each
// device can be mocked independently; enable either or both here, or build with
// -D MOCK_CODE_DETECTOR / -D MOCK_OUTPUT_DEVICE.
//#define MOCK_CODE_DETECTOR   // feed card codes over serial (no card reader)
//#define MOCK_OUTPUT_DEVICE   // print balloon volume to serial (no pump/valve)

// Replace the game loop with the card-reader calibration harness (prints raw
// photoresistor values to serial for picking thresholds). Enable here, or build
// with -D DETECTOR_CALIBRATION. Default (undefined) is the normal game.
//#define DETECTOR_CALIBRATION

// definition of pins
#define PIN_0 0
#define PIN_1 1
#define PIN_2 2
#define PIN_3 3
#define PIN_4 4
#define PIN_5 5
#define PIN_6 6
#define PIN_7 7
#define PIN_8 8
#define PIN_9 9
#define PIN_10 10
#define PIN_11 11
#define PIN_12 12
#define PIN_13 13

// definition of codes
#define CODE_NONE 0
#define CODE_1 1
#define CODE_2 2
#define CODE_3 3
#define CODE_4 4
#define CODE_5 5
#define CODE_6 6
#define CODE_7 7
#define CODE_9 9
#define CODE_10 10
#define CODE_11 11
#define CODE_13 13
#define CODE_14 14
#define CODE_15 15
#define CODE_17 17
#define CODE_19 19
#define CODE_21 21
#define CODE_23 23
#define CODE_27 27
#define CODE_ALL 31

#define CHAR_0 B11111100
#define CHAR_1 B01100000
#define CHAR_2 B11011010
#define CHAR_3 B11110010

#define CHAR_4 B01100110
#define CHAR_5 B10110110
#define CHAR_6 B10111110
#define CHAR_7 B11100000

#define CHAR_8 B11111110
#define CHAR_9 B11110110
#define CHAR_A B11101110
#define CHAR_B B00111110

#define CHAR_C B00011010
#define CHAR_D B01111010
#define CHAR_E B10011110
#define CHAR_F B10001110
#define CHAR_P B11001110

#define CHAR_DOT   B00000001
#define CHAR_MINUS B00000010

#define PLAY_ERROR NOTE_C2

#define NOTE_PAUSE 0
#define NOTE_B0  31
#define NOTE_C1  33
#define NOTE_CS1 35
#define NOTE_D1  37
#define NOTE_DS1 39
#define NOTE_E1  41
#define NOTE_F1  44
#define NOTE_FS1 46
#define NOTE_G1  49
#define NOTE_GS1 52
#define NOTE_A1  55
#define NOTE_AS1 58
#define NOTE_B1  62
#define NOTE_C2  65
#define NOTE_CS2 69
#define NOTE_D2  73
#define NOTE_DS2 78
#define NOTE_E2  82
#define NOTE_F2  87
#define NOTE_FS2 93
#define NOTE_G2  98
#define NOTE_GS2 104
#define NOTE_A2  110
#define NOTE_AS2 117
#define NOTE_B2  123
#define NOTE_C3  131
#define NOTE_CS3 139
#define NOTE_D3  147
#define NOTE_DS3 156
#define NOTE_E3  165
#define NOTE_F3  175
#define NOTE_FS3 185
#define NOTE_G3  196
#define NOTE_GS3 208
#define NOTE_A3  220
#define NOTE_AS3 233
#define NOTE_B3  247
#define NOTE_C4  262
#define NOTE_CS4 277
#define NOTE_D4  294
#define NOTE_DS4 311
#define NOTE_E4  330
#define NOTE_F4  349
#define NOTE_FS4 370
#define NOTE_G4  392
#define NOTE_GS4 415
#define NOTE_A4  440
#define NOTE_AS4 466
#define NOTE_B4  494
#define NOTE_C5  523
#define NOTE_CS5 554
#define NOTE_D5  587
#define NOTE_DS5 622
#define NOTE_E5  659
#define NOTE_F5  698
#define NOTE_FS5 740
#define NOTE_G5  784
#define NOTE_GS5 831
#define NOTE_A5  880
#define NOTE_AS5 932
#define NOTE_B5  988
#define NOTE_C6  1047
#define NOTE_CS6 1109
#define NOTE_D6  1175
#define NOTE_DS6 1245
#define NOTE_E6  1319
#define NOTE_F6  1397
#define NOTE_FS6 1480
#define NOTE_G6  1568
#define NOTE_GS6 1661
#define NOTE_A6  1760
#define NOTE_AS6 1865
#define NOTE_B6  1976
#define NOTE_C7  2093
#define NOTE_CS7 2217
#define NOTE_D7  2349
#define NOTE_DS7 2489
#define NOTE_E7  2637
#define NOTE_F7  2794
#define NOTE_FS7 2960
#define NOTE_G7  3136
#define NOTE_GS7 3322
#define NOTE_A7  3520
#define NOTE_AS7 3729
#define NOTE_B7  3951
#define NOTE_C8  4186
#define NOTE_CS8 4435
#define NOTE_D8  4699
#define NOTE_DS8 4978

#define CHAR_SPACE 32
#define CHAR_TAB 9

#endif // CONSTANTS

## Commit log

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2015-12-03 fixes for arduino micro
    [CodeDetector.cpp]
2015-12-11 fixed memory leak in vector class and added memory diagnostic.
    [Main.cpp]
2015-12-12 fixed thresholds for codedetector
    [CodeDetector.cpp, Main.cpp]
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2026-07-31 assets: migrate curated hardware modules, datasheets, enclosure CAD
    Copy curated Fusion 360 module files (card-reader, display, control),
    component datasheets, order BOM, and enclosure CAD (STEP/STL neutral
    exports plus render PNGs extracted from 180820_BoomBaloon_Device_cpl.zip)
    from the external sync folder into hardware/. Excludes redundant Fritzing
    variants (Steckleiste/90deg), duplicate "_1" datasheets, restricted/
    irrelevant datasheets (Telekom Speedbox, DS_MPE_094/115, jumper/precision
    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
    [180123_bb_dach.stl, 180123_bb_dach.stp, 180123_bb_got_stutzen.stl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]
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2026-07-31 docs: build guide (BOM, modules, enclosure, pin map, firmware build)
    Claude-Session: https://claude.ai/code/session_016Tu8m4fRhUZPZ91oqcB4LB
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2026-07-31 docs: add system block and turn sequence Mermaid diagrams
    Add a flowchart in overview-bom.md showing the four hardware modules
    wired through the Arduino Nano per the verified pin map, and a
    sequenceDiagram in how-it-works.md tracing one turn from card insertion
    through CodeDetector decoding, the Card::playCard factory, optional
    target selection, and the concurrent pump/valve + buzzer + display
    feedback described in the firmware architecture reference.
2026-07-31 docs: correct turn sequence diagram feedback concurrency
    The one-turn sequenceDiagram in how-it-works.md previously showed
    OutputDevice calling PiezoBuzzer and SevenSegmentDisplay concurrently.
    OutputDevice never touches those classes. Corrected to match firmware:
    the accepted buzzer tone is a sequential cue from Game::acceptedFeedback()
    at card acceptance, and the Card (VolumeCard::play) starts the display
    fill animation before calling OutputDevice::apply(); the display animates
    concurrently only because applyIntensities() ticks the scheduler's
    iterate() during its blocking pump/valve loop. Fixed the lead-in
    sentence to match.
2026-07-31 docs: apply final whole-branch review fixes
    - Disclose that the hero photo shows the earlier Arduino Micro
    "prototype 2" build while the firmware targets the Nano
    (caption in docs/index.md and README.md).
    - Commit the Anforderungen Moduswechsel design note as a UTF-8
    static asset and cite it from design-notes.md.
    - Replace the fabricated, self-contradictory calibration example
    in optical-codes.md with a self-consistent Player-1 (code 15)
    snapshot matching CodeDetector's print format.
    - Correct the pcb-boards-overview caption in story.md: the large
    board is the control board (Steuermodul) with Fotomodul/
    Displaymodul/Ablassmotor connector labels; the small one is the
    display m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
2026-07-31 build: migrate firmware from arduino-cmake to PlatformIO
    The legacy arduino-cmake build (Windows/MinGW, ~2013) no longer configures on
    modern CMake (CMake 4 removed pre-3.5 compatibility). Replace it with a single
    platformio.ini defining two Nano environments (old + new bootloader). Verified:
    both envs build cleanly, 16186 B / 52.7% flash, byte-identical to before.
    - Add firmware/platformio.ini, firmware/.gitignore
    - Remove CMakeLists.txt, cmake/ toolchain, arduino-*.bat, .vscode MSVC config
    - Rewrite firmware/README.md and docs build-guide + design-notes for PlatformIO
    - Add .github/workflows/build-firmware.yml (pio run on push)
2026-08-02 brand: add logo, patterned header, and orange palette to the docs
    Extract the logo from the card back (cards/artwork/rueckseite.svg) into
    media/logo/ as a full lockup, a square icon, and favicons, and use them
    across the README and the docs site.
    Dress the docs to match: the card-back weave becomes the header backdrop,
    the site name is set in the cards' own Snap ITC, and the Material palette
    moves from red to oranges sampled from the artwork. Every colour clears
    WCAG AA against the background it sits on, and the wordmark is lifted a
    tenth of its height so its lowercase lines up with the page title beside
    it, which sets in a font with a much smaller x-height.
    Rename the product to "Boom Bal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
2026-08-04 docs+firmware: Micro/Nano board support, placement guide, branding polish
    Firmware:
    - Add a `micro` PlatformIO env (ATmega32U4) for the 2015-2018 prototype board;
    the pin map is unchanged since then so a Micro still runs current firmware.
    - Replace the `nanoatmega328new` env with an inline note on the old/new Nano
    bootloader fallback (the project's clones use the old 57600 bootloader).
    - Fix the LOGGING_ENABLED instructions: use PLATFORMIO_BUILD_FLAGS, not
    `pio run -a` (which passes an avrdude arg, not a compiler flag, so logging
    was silently stripped).
    Docs:
    - Add 'Fitting the Nano in the Micro footprint' to the control-board page,
    with Micro/Nano pinout images and an off-by-one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
2026-08-04 firmware: add serial-mock devices behind MOCKED_DEVICES
    Rename the stale src/Dummy/ subtree to src/Mock/ and revive it as a working
    no-hardware test path, wired in when the firmware is built with -D MOCKED_DEVICES:
    - CodeDetectorMock (was CodeDetectorSerial): feed card codes over serial instead
    of the photoresistors; now also echoes the typed characters back.
    - OutputDeviceMock (was OutputDeviceDummy): print the balloon volume to serial
    after each inflate/deflate as a percentage and an ASCII bar, instead of driving
    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
2026-08-04 firmware: split MOCKED_DEVICES into MOCK_CODE_DETECTOR / MOCK_OUTPUT_DEVICE
    The two mocks are now independent build flags, so a device can be mocked
    while the other stays real:
    - MOCK_CODE_DETECTOR — read card codes from serial (no photoresistor reader)
    - MOCK_OUTPUT_DEVICE — print balloon volume to serial (no pump/valve)
    Main.cpp selects each device separately; Constants.h, the mock headers, the
    Makefile (mock/mock-code/mock-output targets), and the firmware + reference
    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
2026-08-04 firmware: replace ACTIVE_MODE switch with -D DETECTOR_CALIBRATION flag
    The enum-style ACTIVE_MODE()/MODE_GAME()/MODE_CODE_DETECTOR_CALIBRATION()
    machinery is replaced by a single boolean build flag: undefined = normal game
    (default), -D DETECTOR_CALIBRATION = the card-reader calibration harness.
    Converts every #if ACTIVE_MODE() site in Main.cpp and Devices/CodeDetector.*,
    drops the mode defines from Constants.h, adds a make calibrate target, and
    updates platformio.ini and the firmware + reference docs. Both modes build
    cleanly on the Nano.
    Claude-Session: https://claude.ai/code/session_01JCQ45iEtHSWGfSDHFbM3nU
    [CodeDetector.cpp, Constants.h, Main.cpp]
2026-08-04 firmware: keep printf strings in flash and make logging always-on
    printf format strings previously lived in SRAM, so enabling logging cost ~752
    bytes of RAM on the ATmega328P and could overflow the stack. A single macro in
    Constants.h now routes every printf through printf_P(PSTR(...)), keeping the
    format strings in flash; the 3 Serial.print literals in the calibration harness
    use F() for the same reason.
    With logging now essentially free (+16 bytes RAM, +130 bytes flash), the
    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
2026-08-05 docs: enclosure part sub-pages with reproducible 3D renders
    Split the single Enclosure page into an overview + one sub-page per printed
    part (upper/lower housing, roof, hose nozzle, card module) plus a full-assembly
    page, mirroring the Modules structure. Each page has a thumbnail gallery
    (5-up grid, click to zoom), bounding-box dimensions, and STL/STEP links; the
    card module and assembly pages add Boolean cutaway sections.
    Renders are generated from the committed STL models and are reproducible:
    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
2026-08-06 ballon aufsatz
    [260805_got_ballon_aufsatz.stl]
2026-08-06 enclosure: document balloon adapter + nozzle, fix assembly cutaways
    Add the balloon-neck adapter (260805_got_ballon_aufsatz) and the repositioned
    hose nozzle (260805_bb_got_stutzen) to the enclosure docs and the reproducible
    render set:
    - New balloon-adapter.md part page (renders, dimensions, CAD links) with a
    cutaway of the adapter alone and a combined adapter+nozzle section showing the
    continuous bore. Nav and overview parts table updated.
    - Both new parts join the full-assembly renders in shared Creo coords; the
    overview cutaway now notes the centre-axis bore, plus a new "Split apart" pair
    showing the lower half from above and the upper half from below.
    - STEP exports for both ne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
    [260805_bb_got_stutzen.stl, 260805_bb_got_stutzen.stp, 260805_got_ballon_aufsatz.stl]
2026-08-06 docs: add board photo galleries for control, card-reader, and display modules
    Populate the previously empty module galleries with before/after-assembly
    photos, following the media/gallery -> docs assets + square-thumbnail workflow:
    - Control board (Steuermodul): parts spread and the assembled board.
    - Card reader: Lichtmodul and Fotomodul, each with a parts shot and the
    assembled boards.
    - Display (Displaymodul): add the bare PCBs and the assembled set to the
    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
2026-08-10 docs: tighten enclosure overview and fix Dach-Spitze spelling
    Full assembly intro is shorter and descriptive without referencing the
    render pipeline; overall size now includes the balloon adapter and
    nozzle (172x130x110mm, measured from the assembly STLs). Cutaway and
    split-apart sections are merged into one "Interior" section.
    Claude-Session: https://claude.ai/code/session_012UVQUcE67ZTEXJVUoXZoWk
2026-08-10 remove old stutzen files
    [180123_bb_got_stutzen.stl, 180123_bb_got_stutzen.stp]
2026-08-10 hardware: rename enclosure CAD files to plain English kebab-case
    Drop the date-prefixed, German-abbreviated filenames (180820_bb_got,
    260805_got_ballon_aufsatz, ...) now that history lives in git, not the
    filename. Files are renamed to match the part names already used in
    the docs (upper-housing, lower-housing, roof, card-module-housing,
    hose-nozzle, balloon-adapter, full-assembly), and all references in
    render.py, render-all.sh, and the enclosure docs are updated to match.
    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
    [balloon-adapter.stl, card-module-housing.stl, card-module-housing.stp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]
2026-08-11 complete enclosure docs
    [knicklichter.stl, roof-assembly.blend, roof-assembly.stl]
2026-08-11 docs: split build guide overview into System Overview, Modules, and Bill of Materials
    The old "Overview & BOM" page mixed three concerns — the module link
    list, the system description, and the parts table. Split it: the
    module list moves to a new Modules overview page (with a photo of the
    three electronic boards), the BOM moves to its own Reference page, and
    the remaining page is renamed System Overview and starts straight into
    the device description and pin-mapped block diagram.
2026-08-13 docs+media: TIP120 circuit diagram and reproducible PCB image pipeline
    Add a hand-drawn schematic of the TIP120 low-side switch to the control-board
    docs, plus cross-links from System Overview to the module pages.
    Replace the hand-copied PCB top/bottom PNGs (source untracked, likely a
    fab-house Gerber viewer) with a scripted, headless pipeline: Fritzing's
    `-gerber` export -> the open-source tracespace renderer -> Inkscape rasterize,
    wired up as `make pcb` alongside the existing `make wiring`.
2026-08-13 chore: drop leftover WireViz wiring-diagram tooling
    The WireViz-based connector diagrams (media/wiring/, docs/src/assets/img/wiring/,
    the wiring-pinmap.md embed, and the Makefile target) were never committed and
    are no longer wanted — remove the stale reference to them in media/CLAUDE.md.
2026-08-13 docs: fold Design Notes & Roadmap into Firmware Architecture and the card deck
    Retire the standalone Design Notes & Roadmap page — its content now lives
    where it's actually useful: the unbuilt Yin Yang mode-selector and the
    Devices/ dead code move into Firmware Architecture, and a note about the
    never-wired Moduswechsel card moves into the card deck catalog.
    Also trims some player-facing pages (Rules, the card deck table) of internal
    firmware detail that didn't belong there, and a couple of minor doc/asset
    touch-ups (firmware-build.md, arduino-micro-pinout.jpg).
2026-08-13 docs: rename firmware-build.md and wiring-pinmap.md, shorten their nav titles
    firmware-build.md -> firmware.md ("Firmware — Build & Flash" -> "Firmware")
    wiring-pinmap.md -> wiring.md ("Wiring & Pin Map" -> "Wiring")
    Update every cross-reference to the new filenames.
2026-08-13 docs: update the H1 headings on the renamed firmware/wiring pages
    The nav labels were shortened in 23b646c but the page H1s (which drive the
    browser tab title) still read the old "Firmware — Build & Flash" / "Wiring &
    Pin Map".
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2026-08-13 feat: add Lichtmodul.fzpz custom Fritzing part
    Feasibility spike for the system-wiring project: one board, one connector,
    proves the Gerber-to-.fzpz pipeline end to end. Validated three ways:
    structural (well-formed XML, all svgIds resolve), a real headless Fritzing
    round-trip (bundled the part into a throwaway sketch, Fritzing resolved and
    re-exported it with the correct pad coordinates, no errors), and visually
    (rendered breadboard SVG confirms the connector markers land exactly on the
    real LM header holes).
2026-08-13 feat: add Displaymodul.fzpz custom Fritzing part
    Pin 1 isn't marked by a square copper pad here (unlike Lichtmodul), so its
    orientation was cross-checked against the real assembled-board photos
    (displaymodul-top.jpg / -bottom.jpg): the buzzer and header positions
    agree on a 90-degree rotation between the photos and the Gerber render,
    placing pin 1 (Vcc) at the end nearest the buzzer. Validated the same way
    as Lichtmodul (structural + visual marker check).
2026-08-13 feat: add Fotomodul.fzpz custom Fritzing part
    9 connectors: FM (7-pin, to Steuermodul) + LM (2-pin, to Lichtmodul). Pin 1
    for each confirmed from the chamfered corner on their silkscreen outline
    boxes in fotomodul-pcb-top.png.
    The "Connector" 6-pin Displaymodul pass-through documented in
    card-reader.md and visible on the real assembled boards (fotomodul-assembled.jpg)
    is NOT present as a component in Kartenleser_Fotomodul.fzz -- confirmed by
    listing every part instance in the sketch. The design file and the as-built
    boards have drifted apart for this one connector, so it's omitted here
    rather than inventing coordinates with no Gerber data behind them. Worth
    flagging to Dirk separately.
    Val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
2026-08-13 feat: add BoomBalloon-Wiring.fzz starter sketch
    Copies Steuermodul.fzz's real breadboard content (Arduino + TIP120s)
    unchanged and appends unconnected instances of the 3 new custom parts plus
    a generic power jack, positioned but not wired -- ready for Dirk to draw
    the colored wire connections by hand in Fritzing.
    Validated with a real headless Fritzing round-trip: bundled the 3 custom
    parts into a scratch copy the same way Fritzing itself packages non-core
    parts, re-exported via -svg, and confirmed no "module id ... not found"
    errors for any of the 4 new instances (only the same routine per-view
    warnings every board in this project produces) -- the composite output
    contains all of Steuermod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
    [BoomBalloon-Wiring.fzz]
2026-08-13 chore: rename project references to boomballoon org/repo
    GitHub org/repo transferred from d-rk/boomballon to boomballoon/boomballoon
    (correct English spelling of "balloon"); update all GitHub URLs and PCB
    tooling identifiers to match.
2026-08-13 fix: use the real docs PNG for breadboard-view graphics, not vector SVG
    Fritzing's breadboard-view renderer doesn't respect the tracespace vector
    SVG's CSS-based fill styling -- parts built from it show washed out (plain
    white pads, no green/gold) when actually dragged into a sketch, confirmed
    against a screenshot from the real Fritzing GUI. Switch all three parts to
    embed the curated docs PNG (docs/src/assets/img/<board>-pcb-top.png) as a
    raster <image> instead, matching how real official Fritzing parts with
    photographic artwork (e.g. DRV8825_breakout) do it -- including using a
    plain href attribute, not just xlink:href, which that part's own SVG
    revealed as the working convention.
    Also ad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
2026-08-15 feat: finish system wiring, regen Fotomodul/Displaymodul assets, shrink .fzpz parts
    Fotomodul and Displaymodul .fzz sources were corrected from a stale state
    (Fotomodul gained its previously-missing 6-pin Displaymodul pass-through
    connector; Displaymodul's header layout changed). Regenerated the PCB
    top/bottom PNGs and rebuilt both custom Fritzing parts, re-verifying every
    connector position against the new Gerber data and the real assembled-board
    photos rather than trusting the old hand-checked coordinates.
    Shrank every custom .fzpz by 40-49% (Steuermodul less so, dominated by its
    untouched PCB vector SVG): icon view is now a small dedicated thumbnail
    instead of a full-resolution duplicate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
    [BoomBalloon-Wiring.fzz, Displaymodul.fzz, Kartenleser_Fotomodul.fzz]
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
